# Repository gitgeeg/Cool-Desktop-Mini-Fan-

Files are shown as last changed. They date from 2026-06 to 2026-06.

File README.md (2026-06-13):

本作品旨在设计一款基于 ESP12F微控制器的智能桌面风扇控制器，具有PWM无级调速、自然风模式、VFD指示屏、ARGB灯光、联网时间显示以及检测环境光自动调整亮度的功能
-（是我的通用技术作业）
-This project aims to design an intelligent desktop fan controller based on the ESP12F microcontroller, featuring PWM continuous speed control, natural wind mode, VFD display screen, ARGB lighting, online time display, and the function of automatically adjusting brightness based on ambient light detection. 
-(This is my general technical assignment)
jpg

【通用技术作业实录】 https://www.bilibili.com/video/BV1krV56mEhq/?share_source=copy_web&vd_source=b246e824253217c284212f61fc7883cc
-此为该项目制作过程，该项目为搭棚焊接，暂无PCB图，原理图展示了硬件链接。附件有模型和源代码供各位参考
-推荐使用VS code + platformio插件 进行开发和固件下载
-加qq群546926675 一起讨论吧

[General Technology Project Record] https://www.bilibili.com/video/BV1krV56mEhq/?share_source=copy_web&vd_source=b246e824253217c284212f61fc7883cc
-This is the production process of this project. The project involves building a shed and welding. There is no PCB diagram yet. The schematic diagram shows the hardware connections. The attachment includes models and source codes for your reference.
-It is recommended to use VS code + platformio plugin for development and firmware download.
-Join the QQ group 546926675 to discuss together.

-Design process:
-Initially, it was envisioned to create a modular 12CM fan controller with a built-in 21700 battery and a long strip LCD screen. However, due to time and safety considerations, it was changed to using the existing and mature VFD display and an external power supply solution.
The VFD display module was a project designed by myself in March this year. At that time, I wrote mature and usable ESP12F driver code, and the open-source project link is: https://oshwhub.com/git-key/mi-ni-vfd-shi-zhong. It has the advantages of high brightness and contrast.
The fan uses Liming S12RW. To ensure an elegant appearance, an anti-rotating ARGB fan was needed. Only this one is available on the market at a reasonable price. The buzzer design was cancelled due to the insufficient pins of ESP12F.
-EC11, push buttons, etc. are all existing materials, suitable for completing this project within one week. The shell was initially made by sandblasted PLA 3D printing, and later, a more resilient and weather-resistant sandblasted PETG was chosen for printing. 
-Aesthetics principle: The color scheme and shape design of this work are elegant. The connection parts of the shell are rounded, the color is beautiful, and the overall design style is minimalist. 
-Innovative principle: The desktop fan is made intelligent and aesthetically pleasing, and a VFD screen design that is not available in the market has been incorporated. 
-Sustainable development principle: All the solder wires, fluxes, etc. in this product are lead-free. The modules comply with the RHOS standard and do not cause heavy metal pollution. The 3D printing materials selected are non-toxic to humans and recyclable and reusable. 
-Safety principle: External power supply, avoiding the risk of battery fire. All circuit soldering points are reinforced with electrical insulation UV glue to ensure safety. 
-Cost Estimation: 
-Limin S12RW fan x 1 24.6
-8-MD-06INKM VFD display 23.5 
-EC11 module 5.2
-ESP12F 5.74
-Resistors, capacitors, inductors 3.28
-Boost IC, LDO, diodes 2.7
-3D printing material cost 1.74
-Total: 24.6 + 23.5 + 5.2 + 5.74 + 3.28 + 2.7 + 1.74 = 66.76 RMB 
-The structure of the work conforms to mechanics: it is compatible with the shear force and the 3D printing layered structure, and the design is exquisite. 
-It offers diverse functions and rich ARGB lighting colors. It is highly extensible. The main control can be connected to WiFi and synchronize time via NTP. In the future, it can also remotely display various contents through ESP now communication, becoming a mobile terminal. 
-The human-computer interaction logic has been thoroughly verified and the design is extremely reasonable. With just the EC11 encoder, one can select fan mode, control ARGB lights, set automatic brightness, and so on.The operation is fast and convenient. 
-Innovation aspect: It is the only open-source project on the market that incorporates a VFD screen into a portable fan, setting a precedent for handheld fans to serve as both decorative items and handheld terminals. 
-Regarding the process of creating this work, it has enhanced my ability to withstand setbacks: I re-welded the main control and the fan twice and made dozens of changes to the model and code. It has also improved my -creativity: I independently completed the entire process of design, welding, 3D modeling, 3D printing adjustment, and embedded programming in less than a week, which has led to significant growth in all aspects of my abilities. 
-Material selection: 1. The VFD display module is an open-source project designed by myself in March this year. At that time, I wrote mature and usable ESP12F driver code, and it has the advantages of high brightness and contrast. 
-2. Materials such as EC11 and microswitches are all available and suitable for completing this project within one week. The outer shell was initially 3D-printed using matte PLA, and later was replaced with a more resilient and weather-resistant matte PETG for printing. 
-3. The photodiode was an element purchased for the previous film camera shutter speed measurement project. Its voltage range of 0 - 600mv is exactly within the sampling range of the microcontroller's ADC. 
-4. The esp12f microcontroller is inexpensive, has Wi-Fi functionality, has a sufficient number of pins and an ADC. It is an excellent choice for this project. 
-5. The 12cm fan uses Liming S12RW. To ensure an elegant appearance, an anti-rotation ARGB fan is required. Only this one is available on the market at a reasonable price. Structure: This controller and the fan body are designed with an upper and lower stacking structure. The center of gravity is at the bottom, which is placed on the desktop for stable and reliable operation, with an elegant appearance. It is connected by a PETG shell and 304 stainless steel m5 15mm screws, providing excellent weather resistance. Function: 
-6. Functions: PWM continuous speed control, natural wind mode, VFD display screen, ARGB lighting, network time display, and automatic brightness adjustment based on ambient light detection. All the functions are included, and the device has excellent maintainability and scalability: USB D+D- pins are linked to the TX/RX interface of the main controller, allowing for program flashing at any time. It can also be remotely controlled via ESP now communication, becoming a mobile terminal. 

-The initial design was for a modular 12CM fan controller that incorporated a built-in 21700 battery and featured a long strip LCD screen. However, due to time constraints and battery safety considerations, it was changed to use the existing and mature VFD display and an external power supply solution. 
-The buzzer design was cancelled because the ESP12F had insufficient pins.

-设计过程：
-最初设想为内置一节21700电池、使用长条形LCD屏幕的模块化12CM风扇控制器，但因时间、安全等因素改为使用现有且成熟的VFD显示屏以及外部供电方案。
-VFD显示模组为今年3月本人自己设计的项目，当时编写了成熟可用的ESP12F驱动代码，开源项目链接：https://oshwhub.com/git-key/mi-ni-vfd-shi-zhong 且具有高亮度与对比度的优点。
-风扇采用利民S12RW ，为了确保外观设计优雅故需要反叶ARGB风扇，市面上价格合适的仅此一款。蜂鸣器设计由于ESP12F引脚不足，故取消。
-EC11与 微动按钮 等材料都是现有的，适合一周内完成该项目。外壳最初采用磨砂PLA 3D打印，后选用更有韧性和耐候性的磨砂PETG打印。

-美观性原则：该作品配色与外形设计优雅，外壳链接部位做圆角处理，配色美观，整体为极简主义设计风格。

-创新性原则：将桌面风扇智能化、美观化并加入了市面上没用的VFD屏幕设计。

-可持续发展原则：该作品焊锡丝、助焊剂等全部无铅，模块符合RHOS标准，不造成重金属污染。3D打印材料选用无人体危害且可回收重复利用的PETG。

-安全性原则：外部供电、避免电池起火危险，全部电路焊接点都使用电气绝缘UV胶加固，保证安全。

-成本估算：

-利民S12RW风扇 x 1 24.6
-8-MD-06INKM VFD显示屏 23.5

-EC11模块 5.2
-ESP12F 5.74
-电阻、电容、电感元件 3.28
-升压IC 、LDO 、二极管 2.7
-3D打印材料费 1.74
-总计：24.6+23.5+5.2+5.74+3.28+2.7+1.74= 66.76人民币

-作品结构符合力学：抗剪切力和3D打印结构层叠结构相符，设计精巧

-实现功能多样，ARGB灯光色彩丰富。可扩展新极佳，主控可连接WiFi ntp同步时间，未来更可通过ESP now通讯远程显示各种内容，成为移动化终端。

-人机交互逻辑通过反复验证设计的十分合理，仅通过EC11编码器就可以选择风扇模式、控制ARGB灯光、设置自动亮度等等，操作快捷方便。

-创新方面：为市面上唯一将VFD屏幕加入到便携风扇的开源作品，开创了手持风扇作为摆件和手持终端双功能的先例。

-对于制作该作品的过程，锻炼了本人的抗挫能力：重新焊接主控和风扇各两次、数十次更改模型和代码。提升了本人的创造能力：仅仅用时一周不到独立完成了设计、焊接、3D建模、3D打印调参、嵌入式编程的全过程，使得自己各方面都得到了显著成长。

-选材： 
-1.VFD显示模组为今年3月本人自己设计的开源项目，当时编写了成熟可用的ESP12F驱动代码， 且具有高亮度与对比度的优点。

-2.EC11与 微动按钮 等材料都是现有的，适合一周内完成该项目。外壳最初采用磨砂PLA 3D打印，后选用更有韧性和耐候性的磨砂PETG打印。

-3.光电二极管为之前胶片相机快门测速器项目购买的元件，其电压范围0-600mv正好在微控制器adc的采样范围之内。

-4.esp12f微控制器价格低廉，有wifi功能，引脚数量够多且拥有一个adc。是本项目的极佳选择。

-5. 12cm风扇采用利民S12RW ，为了确保外观设计优雅故需要反叶ARGB风扇，市面上价格合适的仅此一款。 结构：本控制器与风扇主体采用上下堆叠设计，重心在下摆放在桌面稳定可靠，外形优雅。使用PETG外壳和304不锈钢m5 15mm螺丝连接件，耐候性极佳。 功

-6.功能：PWM无级调速、自然风模式、VFD指示屏、ARGB灯光、联网时间显示以及检测环境光自动调整亮度。功能应有尽有，且可维护性和扩展性极佳：usb d+d-引脚链接主控的TX/RX接口，可随时刷写程序。更可通过ESP now通讯远程控制，成为移动化终端。

-最初设想为内置一节21700电池、使用长条形LCD屏幕的模块化12CM风扇控制器，但因时间、电池安全等因素改为使用现有且成熟的VFD显示屏以及外部供电方案。

-蜂鸣器设计由于ESP12F引脚不足，故取消。

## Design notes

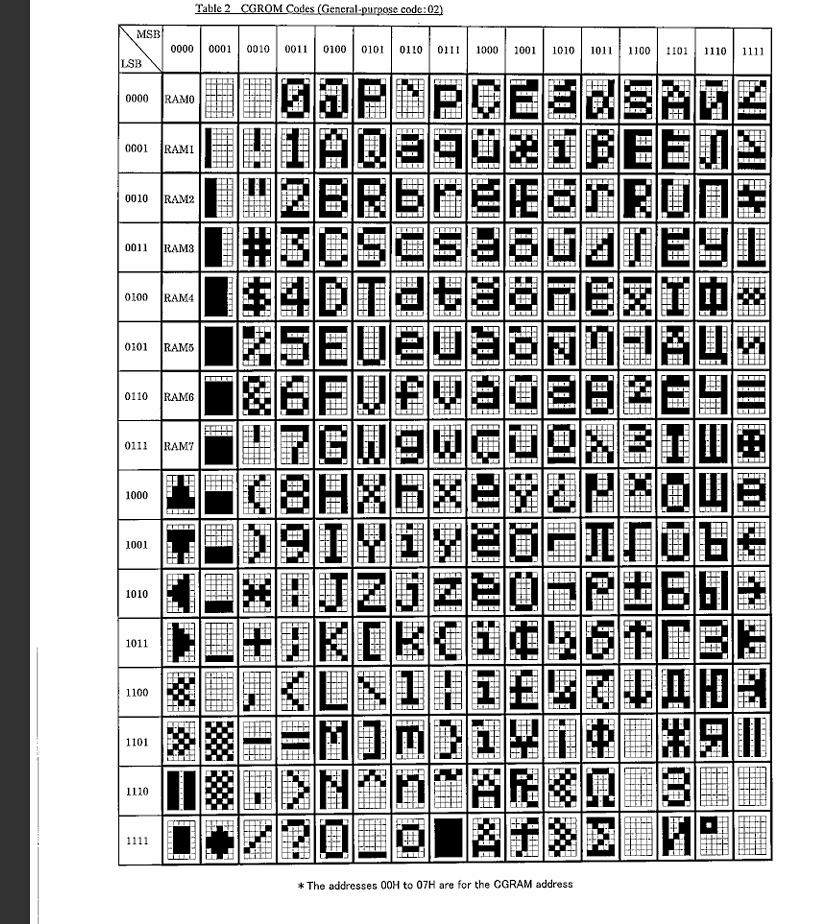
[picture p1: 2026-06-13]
Snipaste_2026-05-24_10-11-24.png

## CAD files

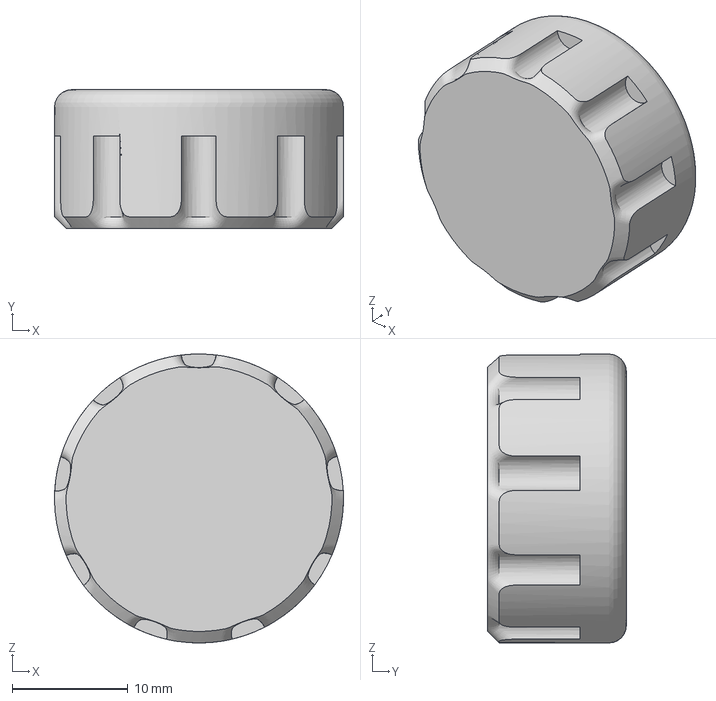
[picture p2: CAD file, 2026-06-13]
旋钮.3mf
25.0 x 12.0 x 25.0 mm

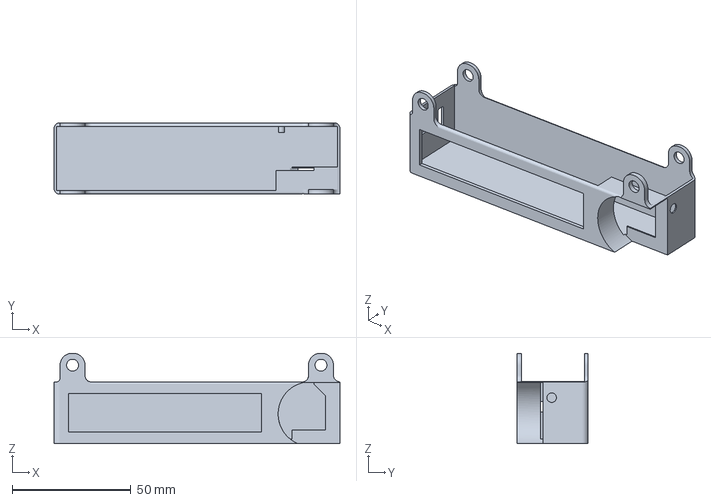
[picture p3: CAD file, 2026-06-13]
Fan.3mf
120.2 x 30.0 x 38.0 mm

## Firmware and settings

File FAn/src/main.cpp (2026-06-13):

/**
 * 智能风扇控制器 - ESP12F
 * ===========================
 * 功能:
 *   - PT6302 VFD 8位显示屏驱动
 *   - EC11 旋转编码器 (旋转+按压+长按+双击)
 *   - PWM 风扇速度控制
 *   - WS2812B ARGB 灯光控制
 *   - 光电二极管自动亮度调节
 *   - 自然风模式 (山谷回风)
 *   - 设置菜单 (省电模式 / 手动亮度)
 */

#include <Arduino.h>
#include <FastLED.h>
#include <ESP8266WiFi.h>
#include <time.h>

// ============================================================
// 1. 引脚定义
// ============================================================
// VFD 显示屏 (PT6302)
#define VFD_DIN   14   // DA 数据输入
#define VFD_CLK   16   // CK 时钟
#define VFD_CS    15   // CS 片选
#define VFD_RST   13   // RS 复位

// EC11 旋转编码器 (按键通过 A/B 序列超时检测, 无独立GPIO)
#define EC11_A    4    // GA  A相 (GPIO4)
#define EC11_B    12   // BB  B相 (GPIO12)

// 风扇
#define FAN_PWM   2    // PWM 风扇调速
#define FAN_ARGB  5    // ARGB 灯控 (WS2812B)

// 光电二极管 (ESP12F ADC / TOUT)
#define PHOTO_ADC A0   // 模拟输入 0-1V

// GPIO0 按键 (默认高电平, 低电平=按下, 用于开关风扇+RGB)
#define BTN_GPIO0 0

// ============================================================
// 2. 常量定义
// ============================================================

// --- VFD 显示位数 ---
#define VFD_DIGITS 8

// --- VFD 自定义字符 (PT6302 CGRAM / ROM) ---
// 风速档位条: 1竖 ~ 5竖
#define VFD_CHAR_BAR1   0x11
#define VFD_CHAR_BAR2   0x12
#define VFD_CHAR_BAR3   0x13
#define VFD_CHAR_BAR4   0x14
#define VFD_CHAR_BAR5   0x15
// 箭头
#define VFD_CHAR_LARROW 0x0A  // 左箭头
#define VFD_CHAR_RARROW 0x0B  // 右箭头
// 最小风速全亮
#define VFD_CHAR_ALLON  0x1D
// 风车动画帧
#define VFD_CHAR_PIPE   0x7C  // '|'
#define VFD_CHAR_SLASH  0x2F  // '/'
#define VFD_CHAR_DASH   0x2D  // '-'
#define VFD_CHAR_BSLASH 0x5C  // '\'
// 空格与空白
#define VFD_CHAR_SPACE  0x20
#define VFD_CHAR_BLANK  0x10

// --- 风速档位 (13档: 0关, 1=2格, 2~12每档+3格, 12级满35格) ---
#define FAN_LEVELS      13    // 0~12档
#define FAN_DISPLAY_POS 7     // 显示档位条的位置数 (1-7位)
#define FAN_BARS_PER_POS 5    // 每位置5段 (BAR1~BAR5)
// 13档位→格子数: level0=0, level1=2, level_n(2~12)=2+3*(n-1)
#define FAN_LEVEL1_BARS 2     // 第一档格子数
#define FAN_BARS_PER_STEP 3   // 之后每档+3格

// --- ARGB 灯光颜色模式 ---
enum ArgbMode : uint8_t {
    ARGB_SPEED_COLOR = 0,  // 随风扇档位变速 (蓝→黄→红)
    ARGB_BLUE,             // 浅蓝
    ARGB_WHITE,            // 白
    ARGB_ORANGE,           // 亮橙
    ARGB_RED,              // 红
    ARGB_RGB_CYCLE,        // 转圈RGB(逐灯珠)
    ARGB_RGB_ALL_CYCLE,    // 全体一起变RGB
    ARGB_OFF,              // 关闭
    ARGB_MODE_COUNT
};

// --- ARGB 灯光电源状态 ---
enum ArgbPower : uint8_t {
    ARGB_POWER_ON = 0,
    ARGB_POWER_OFF
};

// --- ARGB 亮度模式 ---
enum ArgbBrightMode : uint8_t {
    ARGB_BRIGHT_AUTO = 0,  // 跟随环境光
    ARGB_BRIGHT_MANUAL     // 手动
};

// --- 菜单/页面状态 ---
enum Page : uint8_t {
    PAGE_HOME = 0,          // 首页 - 风扇速度显示
    PAGE_ARGB_CONTROL,      // ARGB 灯光控制
    PAGE_SETTINGS,          // 设置菜单
    PAGE_POWER_SAVE,        // 省电模式设置
    PAGE_BRIGHTNESS_MANUAL, // 手动亮度调节
    PAGE_TIME               // 时间显示页面
};

// --- 设置项索引 ---
#define SETTING_POWER_SAVE      0
#define SETTING_BRIGHTNESS      1
#define SETTING_TIME            2
#define SETTING_COUNT           3

// --- 风扇模式 ---
enum FanMode : uint8_t {
    FAN_CONSTANT = 0,   // 定速模式
    FAN_NATURAL         // 自然风模式 (仅山谷回风)
};

// --- 亮度模式 ---
enum BrightnessMode : uint8_t {
    BRIGHT_AUTO = 0,    // 自动亮度
    BRIGHT_MANUAL       // 手动亮度
};

// --- 时间常量 (ms) ---
#define LONG_PRESS_MS       200   // ≥500ms=长按, <500ms=单点
#define DOUBLE_CLICK_MS     400
#define IDLE_TIMEOUT_MS     6000  // 6s无操作回首页
#define POWER_SAVE_IDLE_MS  5000
#define SPINNER_INTERVAL_MS 200
#define FAN_ADJ_TIMEOUT_MS  550   // 调速箭头快速恢复为风车动画

// --- 光电二极管 ADC 阈值 (ESP8266 10-bit ADC: 0-1023 对应 0-1V) ---
// 380mV→389 | 310mV→317 | 280mV→287 | 50mV→51
#define ADC_DARKEST    51
#define ADC_BRIGHTEST  389   // 380mV时屏幕亮度已达最大

// --- 亮度映射 ---
#define VFD_BRIGHT_MIN  40
#define VFD_BRIGHT_MAX  255

// --- ARGB LED 数量 (共15个灯珠) ---
#define ARGB_NUM_LEDS 15

// ============================================================
// 3. 全局变量
// ============================================================

// --- VFD 显示缓冲区 ---
uint8_t vfdPrevBuffer[VFD_DIGITS];

// --- EC11 编码器状态 (双下降沿 + 先后顺序) ---
volatile int32_t  encPosition = 0;        // 累计旋转位置
volatile int8_t   encSeqState = 0;        // 0=空闲 1=GA先低 2=BB先低
volatile unsigned long encGaFallMs = 0;   // GA下降时刻(ms)
volatile unsigned long encPressDuration = 0; // 按键持续时间ms (0=无)
int32_t  encLastRead = 0;

// 按键处理 (loop中消费 encPressDuration)
unsigned long encLastClickTime = 0;
uint8_t  encClickCount = 0;
bool     encClickPending = false;

// --- 编码器事件 ---
enum EncEvent : uint8_t {
    ENC_NONE = 0,
    ENC_ROTATE_CW,
    ENC_ROTATE_CCW,
    ENC_SINGLE_CLICK,
    ENC_DOUBLE_CLICK,
    ENC_LONG_PRESS
};

// --- 系统状态 ---
Page            currentPage = PAGE_HOME;
Page            prevPage = PAGE_HOME;
FanMode         fanMode = FAN_CONSTANT;
uint8_t         fanSpeed = 4;           // 当前档位 0~12 (默认中档)
uint8_t         fanDisplaySpeed = 6;    // 定速模式显示用档位
uint8_t         fanDisplaySmoothed = 0; // 自然风平滑显示用的竖格数 (0~35)
uint8_t         fanCurrentPWM = 0;      // 当前实际 PWM (平滑过渡)
uint8_t         fanTargetPWM = 0;       // 目标 PWM
bool            fanAdjusting = false;
bool            fanAdjustDir = true;

// --- ARGB 状态 ---
ArgbPower      argbPower = ARGB_POWER_ON;
ArgbMode       argbCurrentMode = ARGB_SPEED_COLOR;
ArgbMode       argbPreviewMode = ARGB_SPEED_COLOR;
ArgbBrightMode argbBrightMode = ARGB_BRIGHT_AUTO;
uint8_t        argbBrightness = 28;
uint8_t        argbManualBrightness = 128;
uint8_t        argbPreviewBrightness = 128;
uint16_t       argbCountIndex = 0;
unsigned long  argbCycleLastMs = 0;
bool           argbBrightnessMode = false;
uint8_t        argbRenderHue = 0;
uint8_t        argbSpeedHue = 160;        // SPEED_COLOR平滑目标色相
bool           argbInArgbPage = false;
CRGB           argbLeds[ARGB_NUM_LEDS];

// --- 亮度控制 ---
BrightnessMode  brightMode = BRIGHT_AUTO;
uint8_t         vfdBrightness = 200;
uint8_t         vfdManualBrightness = 200;
bool            powerSaveEnabled = true;

// --- GPIO0 按键状态 (开关风扇+RGB) ---
bool            gpio0PowerOn = true;       // 当前电源状态
bool            gpio0LastState = true;     // 上次GPIO0电平 (默认高)
unsigned long   gpio0DebounceMs = 0;       // 防抖计时
uint8_t         gpio0SavedFanSpeed = 6;    // 保存的风扇档位 0~12
FanMode         gpio0SavedFanMode = FAN_CONSTANT; // 保存的风扇模式
ArgbMode       gpio0SavedArgbMode = ARGB_SPEED_COLOR; // 保存的ARGB模式
uint8_t        gpio0SavedArgbBrightness = 128;      // 保存的ARGB亮度

// --- 自然风状态 (仅山谷回风) ---
unsigned long   naturalCycleStart = 0;
unsigned long   valleyGustNext = 0;
unsigned long   valleyCalmNext = 0;
bool            valleyInGust = false;
bool            valleyInCalm = false;

// --- 计时器 ---
unsigned long   lastUserAction = 0;
unsigned long   lastSpinnerUpdate = 0;
uint8_t         spinnerFrame = 0;

// --- 设置菜单 ---
bool            timeDisplayEnabled = true;  // 时间显示开关
uint8_t         settingIndex = 0;

// ============================================================
// 4. VFD 显示驱动
// ============================================================

void vfdWriteByte(uint8_t data) {
    for (uint8_t i = 0; i < 8; i++) {
        digitalWrite(VFD_CLK, LOW);
        digitalWrite(VFD_DIN, (data & 0x01) ? HIGH : LOW);
        data >>= 1;
        digitalWrite(VFD_CLK, HIGH);
    }
}

void vfdShow() {
    digitalWrite(VFD_CS, LOW);
    vfdWriteByte(0xE8);
    digitalWrite(VFD_CS, HIGH);
}

void vfdInit() {
    digitalWrite(VFD_CS, LOW);
    vfdWriteByte(0xE0);
    delayMicroseconds(5);
    vfdWriteByte(0x07);  // 8位
    digitalWrite(VFD_CS, HIGH);
    delayMicroseconds(5);

    digitalWrite(VFD_CS, LOW);
    vfdWriteByte(0xE4);
    delayMicroseconds(5);
    vfdWriteByte(200);
    digitalWrite(VFD_CS, HIGH);
    delayMicroseconds(5);
}

void vfdSetBrightness(uint8_t brightness) {
    digitalWrite(VFD_CS, LOW);
    vfdWriteByte(0xE4);
    delayMicroseconds(5);
    vfdWriteByte(brightness);
    digitalWrite(VFD_CS, HIGH);
    vfdBrightness = brightness;
}

void vfdWriteChar(uint8_t pos, uint8_t chr) {
    digitalWrite(VFD_CS, LOW);
    vfdWriteByte(0x20 + pos);
    vfdWriteByte(chr);
    digitalWrite(VFD_CS, HIGH);
}

void vfdClear() {
    for (uint8_t i = 0; i < VFD_DIGITS; i++) {
        vfdWriteChar(i, VFD_CHAR_BLANK);
        vfdPrevBuffer[i] = 0xFF;
    }
    vfdShow();
}

void vfdSetBuffer(const uint8_t* buf) {
    bool changed = false;
    for (uint8_t i = 0; i < VFD_DIGITS; i++) {
        if (buf[i] != vfdPrevBuffer[i]) {
            vfdWriteChar(i, buf[i]);
            vfdPrevBuffer[i] = buf[i];
            changed = true;
        }
    }
    if (changed) vfdShow();
}

// ============================================================
// 5. EC11 编码器中断处理
// ============================================================
// 同时检测 GA/BB 下降沿, 按先后顺序判定旋转
//   右旋 CW: BB↓先 → GA↓后 (BB先低)
//   左旋 CCW: GA↓先 → BB↓后 (GA先低)
// 按键: GA↓后 BB始终为HIGH, GA↑时记录持续时间
//        < 500ms → 单点 | ≥ 500ms → 长按
//
// 状态: 0=空闲 1=GA先低 2=BB先低
// 旋转: BB↓先→GA↓后=CW | GA↓先→BB↓后=CCW
// 按键: GA↓→GA↑且BB始终HIGH, 时长<100ms单点 ≥100ms长按

void IRAM_ATTR encISR() {
    uint8_t a = digitalRead(EC11_A);
    uint8_t b = digitalRead(EC11_B);

    if (a == LOW && b == LOW) {
        if (encSeqState == 1) encPosition--;
        if (encSeqState == 2) encPosition++;
        encSeqState = 0;
    }
    else if (a == LOW && b == HIGH) {
        if (encSeqState == 0) { encSeqState = 1; encGaFallMs = millis(); }
    }
    else if (a == HIGH && b == LOW) {
        if (encSeqState == 0) encSeqState = 2;
        if (encSeqState == 1) encSeqState = 0;
    }
    else {
        if (encSeqState == 1) {
            unsigned long dur = millis() - encGaFallMs;
            if (dur >= 80) encPressDuration = dur;
        }
        encSeqState = 0;
    }
}

void encInit() {
    pinMode(EC11_A, INPUT_PULLUP);
    pinMode(EC11_B, INPUT_PULLUP);
    attachInterrupt(digitalPinToInterrupt(EC11_A), encISR, CHANGE);
    attachInterrupt(digitalPinToInterrupt(EC11_B), encISR, CHANGE);
}

EncEvent encPoll() {
    unsigned long now = millis();
    static unsigned long lastEncEvent = 0;  // 统一防抖: 100ms内只记录首次操作

    // --- 1. 处理旋转 (位置变化) ---
    int32_t pos;
    noInterrupts();
    pos = encPosition;
    interrupts();

    if (pos != encLastRead) {
        int32_t old = encLastRead;
        encLastRead = pos; // 更新位置, 丢弃中间步数
        if (now - lastEncEvent >= 100) {
            EncEvent evt = (pos > old) ? ENC_ROTATE_CW : ENC_ROTATE_CCW;
            lastEncEvent = now;
            lastUserAction = now;
            return evt;
        }
    }

    // --- 2. 处理按键 (ISR记录的持续时间) ---
    unsigned long pressDur;
    noInterrupts();
    pressDur = encPressDuration;
    encPressDuration = 0;
    interrupts();

    if (pressDur > 0 && (now - lastEncEvent >= 100)) {
        lastEncEvent = now;
        lastUserAction = now;
        if (pressDur >= LONG_PRESS_MS) {
            encClickPending = false;
            encClickCount = 0;
            return ENC_LONG_PRESS;
        } else {
            encClickCount++;
            if (encClickCount == 1) {
                encLastClickTime = now;
                encClickPending = true;
            } else if (encClickCount >= 2) {
                encClickPending = false;
                encClickCount = 0;
                return ENC_DOUBLE_CLICK;
            }
        }
    }

    // --- 3. 单击超时判定 ---
    if (encClickPending && (now - encLastClickTime > DOUBLE_CLICK_MS)) {
        encClickPending = false;
        encClickCount = 0;
        lastEncEvent = now;
        lastUserAction = now;
        return ENC_SINGLE_CLICK;
    }

    return ENC_NONE;
}

// ============================================================
// 6. 风扇 PWM 控制 (35档 + 平滑变速)
// ============================================================

void fanInit() {
    pinMode(FAN_PWM, OUTPUT);
    analogWriteFreq(18000);  // 25kHz 静音 ******
    analogWrite(FAN_PWM, 0);
    fanCurrentPWM = 0;
    fanTargetPWM = 0;
}

/**
 * 设置风扇目标档位 (0-11), PWM 平滑过渡在 fanSmoothUpdate() 中完成
 */
void fanSetSpeed(uint8_t level) {
    if (level > 12) level = 12;
    fanTargetPWM = (level == 0) ? 0 : map(level, 1, 12, 20, 255);
    fanDisplaySpeed = level;
}

/**
 * 设置目标百分比 (0-100), 用于自然风模式
 * 显示档位由 fanCurrentPWM 实时反算, 确保平滑
 */
void fanSetTargetPercent(uint8_t percent) {
    if (percent > 100) percent = 100;
    fanTargetPWM = (percent == 0) ? 0 : map(percent, 1, 100, 20, 255);
}

/**
 * 将当前 PWM 反算为显示档位 (0-11)
 */
uint8_t pwmToDisplayLevel(uint8_t pwm) {
    if (pwm == 0) return 0;
    return constrain(map(pwm, 20, 255, 1, 12), 1, 12);
}

/**
 * 平滑过渡 PWM (每帧调用, 渐进式变速)
 */
void fanSmoothUpdate() {
    if (fanCurrentPWM == fanTargetPWM) return;

    int16_t diff = (int16_t)fanTargetPWM - (int16_t)fanCurrentPWM;
    int16_t step;

    // 步长: 加速快一些, 减速慢一些(更自然)
    if (abs(diff) > 50) {
        step = (diff > 0) ? 8 : -5;   // 大步快调
    } else if (abs(diff) > 10) {
        step = (diff > 0) ? 4 : -2;   // 中步
    } else {
        step = (diff > 0) ? 1 : -1;   // 微步精调
    }

    fanCurrentPWM = constrain(fanCurrentPWM + step, 0, 255);
    analogWrite(FAN_PWM, fanCurrentPWM);
}

/**
 * 立即设置 PWM (跳过平滑)
 */
void fanSetRawSpeed(uint8_t speed) {
    fanCurrentPWM = speed;
    fanTargetPWM = speed;
    analogWrite(FAN_PWM, speed);
}

/**
 * 设置目标百分比 (已废弃, 用 fanSetTargetPercent)
 */
void fanSetPercent(uint8_t percent) {
    fanSetTargetPercent(percent);
}

// ============================================================
// 7. ARGB 灯光控制 (WS2812B)
// ============================================================
// 前向声明 (第8节定义)
uint16_t photoRead();
uint8_t photoToBrightness(uint16_t adc);

void argbInit() {
    FastLED.addLeds<WS2812B, FAN_ARGB, GRB>(argbLeds, ARGB_NUM_LEDS);
    FastLED.setBrightness(128);
    FastLED.clear();
    ets_intr_lock();
    FastLED.show();
    delayMicroseconds(100);
    FastLED.show();
    ets_intr_unlock();
}

/** 全部熄灭 (硬件级中断锁+双重发送) */
void argbAllOff() {
    FastLED.clear();
    uint8_t pwmVal = fanCurrentPWM;
    digitalWrite(FAN_PWM, LOW);
    ets_intr_lock();
    FastLED.show();
    delayMicroseconds(100);
    FastLED.show();
    ets_intr_unlock();
    analogWrite(FAN_PWM, pwmVal);
}

/** 根据模式刷新所有灯珠 */
void argbRender(ArgbMode mode, uint8_t brightness) {
    FastLED.setBrightness(brightness);
    FastLED.clear();

    switch (mode) {
        case ARGB_SPEED_COLOR:
            // 风扇档位→颜色: 低=蓝(160°) 中=黄(64°) 高=红(0°), 3s完成全程平滑
            {
                uint8_t target = map(fanCurrentPWM, 0, 255, 160, 0);
                // 每200ms步进10, 全程160/10=16步=3.2s≈3s
                int16_t diff = (int16_t)target - (int16_t)argbSpeedHue;
                if (diff > 0) { argbSpeedHue += (diff > 10) ? 10 : diff; }
                else if (diff < 0) { argbSpeedHue -= ((-diff) > 10) ? 10 : (-diff); }
                fill_solid(argbLeds, ARGB_NUM_LEDS, CHSV(argbSpeedHue, 255, 255));
            }
            break;
        case ARGB_BLUE:
            fill_solid(argbLeds, ARGB_NUM_LEDS, CRGB(0, 255, 200)); 
            break;
        case ARGB_ORANGE:
            fill_solid(argbLeds, ARGB_NUM_LEDS, CRGB(255, 60, 0)); 
            break;
        case ARGB_WHITE:
            fill_solid(argbLeds, ARGB_NUM_LEDS, CRGB::White);
            break;
        case ARGB_RED:
            fill_solid(argbLeds, ARGB_NUM_LEDS, CRGB::Red);
            break;
        case ARGB_RGB_CYCLE:
            for (uint16_t i = 0; i < ARGB_NUM_LEDS; i++) {
                argbLeds[i] = CHSV((uint8_t)(argbRenderHue + i * (255 / ARGB_NUM_LEDS)), 255, 255);
            }
            break;
        case ARGB_RGB_ALL_CYCLE:
            fill_solid(argbLeds, ARGB_NUM_LEDS, CHSV(argbRenderHue, 255, 255));
            break;
        case ARGB_OFF:
            break;
        default: break;
    }
    // 硬件级中断锁 + 临时静默PWM引脚 + 双重发送抗噪声
    uint8_t pwmVal = fanCurrentPWM;            // 保存当前PWM
    digitalWrite(FAN_PWM, LOW);                // PWM引脚拉低, 减少噪声
    ets_intr_lock();                           // 硬件级关全部中断
    FastLED.show();                            // 第一次发送
    delayMicroseconds(100);                    // 等待噪声消退
    FastLED.show();                            // 第二次发送 (覆盖残留错误)
    ets_intr_unlock();                         // 恢复中断
    analogWrite(FAN_PWM, pwmVal);              // 恢复PWM
}

static unsigned long argbLastRender = 0;  // 统一渲染计时

/** 切换模式/页面时重置渲染定时器, 确保立即响应 */
void argbResetRenderTimer() { argbLastRender = 0; }

/** RGB色相 + SPEED_COLOR定时刷新 (统一计时器, 无延迟) */
void argbCycleUpdate() {
    unsigned long now = millis();
    if (currentPage == PAGE_ARGB_CONTROL || argbPower != ARGB_POWER_ON) return;

    // 统一计时: RGB 50ms, SPEED_COLOR 200ms, 其余不刷
    uint16_t interval = 200;
    if (argbCurrentMode == ARGB_RGB_CYCLE || argbCurrentMode == ARGB_RGB_ALL_CYCLE) interval = 50;
    else if (argbCurrentMode != ARGB_SPEED_COLOR) return;

    if (now - argbLastRender < interval) return;
    argbLastRender = now;

    if (argbCurrentMode == ARGB_RGB_CYCLE || argbCurrentMode == ARGB_RGB_ALL_CYCLE) {
        argbRenderHue++;
    }
    argbRender(argbCurrentMode, argbBrightness);
}

/** ARGB 亮度自动更新 (跟随环境光, 关中断刷新) */
void argbBrightnessUpdate() {
    if (argbBrightMode != ARGB_BRIGHT_AUTO) return;
    static unsigned long lastUpdate = 0;
    unsigned long now = millis();
    if (now - lastUpdate < 300) return;  // 加快到300ms
    lastUpdate = now;

    uint8_t target = photoToBrightness(photoRead());
    // 步进3, 加速响应
    if (argbBrightness < target) argbBrightness += min(3, target - argbBrightness);
    else if (argbBrightness > target) argbBrightness -= min(3, argbBrightness - target);

    FastLED.setBrightness(argbBrightness);
    if (currentPage == PAGE_ARGB_CONTROL) {
        if (argbBrightnessMode) argbPreviewBrightness = argbBrightness;
    } else {
        uint8_t pwmVal = fanCurrentPWM;
        digitalWrite(FAN_PWM, LOW);
        ets_intr_lock();
        FastLED.show();
        delayMicroseconds(100);
        FastLED.show();
        ets_intr_unlock();
        analogWrite(FAN_PWM, pwmVal);
    }
}

// ============================================================
// 8. 光电二极管 & 自动亮度 (3秒滑动平均)
// ============================================================

#define ADC_SAMPLE_MS   1000  // 每1s采样一次
#define ADC_WINDOW      3     // 3s / 1s = 3个样本

static uint16_t adcBuffer[ADC_WINDOW] = {0};
static uint8_t  adcIndex = 0;
static uint16_t adcSum = 0;
static uint8_t  adcCount = 0;

/**
 * 读取光电二极管 ADC (3秒滑动平均)
 */
uint16_t photoRead() {
    static unsigned long lastSample = 0;
    unsigned long now = millis();
    if (now - lastSample >= ADC_SAMPLE_MS) {
        lastSample = now;
        uint16_t raw = analogRead(PHOTO_ADC);
        if (adcCount < ADC_WINDOW) {
            adcSum += raw;
            adcCount++;
        } else {
            adcSum = adcSum - adcBuffer[adcIndex] + raw;
        }
        adcBuffer[adcIndex] = raw;
        adcIndex = (adcIndex + 1) % ADC_WINDOW;
    }
    if (adcCount == 0) return analogRead(PHOTO_ADC);
    return adcSum / adcCount;
}
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
void loop() {
    unsigned long now = millis();

    // 1. 编码器事件
    EncEvent event = encPoll();
    if (event != ENC_NONE) {
        handleEncEvent(event);
        lastUserAction = now;
    }

    // 1b. GPIO0 按键检测 (低电平=按下, 防抖50ms)
    bool gpio0Curr = digitalRead(BTN_GPIO0);
    if (gpio0Curr == LOW && gpio0LastState == HIGH) {
        gpio0DebounceMs = now;
    }
    if (gpio0Curr == HIGH && gpio0LastState == LOW && (now - gpio0DebounceMs >= 50)) {
        if (gpio0PowerOn) {
            // 关闭: 仅停风扇, ARGB保持开启, 保存模式状态
            gpio0SavedFanSpeed = fanSpeed;
            gpio0SavedFanMode = fanMode;
            gpio0SavedArgbMode = argbCurrentMode;
            gpio0SavedArgbBrightness = argbBrightness;
            fanSetRawSpeed(0);
            fanMode = FAN_CONSTANT;
            gpio0PowerOn = false;
            // 切换到首页显示 0x1D
            if (currentPage != PAGE_HOME) switchPage(PAGE_HOME);
            Serial.println("[GPIO0] 关闭风扇");
        } else {
            // 开启: 恢复风扇和模式
            fanSpeed = gpio0SavedFanSpeed;
            fanMode = gpio0SavedFanMode;
            if (fanMode == FAN_CONSTANT) {
                fanSetSpeed(fanSpeed);
            } else {
                naturalCycleStart = millis();
                valleyGustNext = valleyCalmNext = 0;
                valleyInGust = valleyInCalm = false;
                fanSetSpeed(fanSpeed);
            }
            gpio0PowerOn = true;
            if (currentPage != PAGE_HOME) switchPage(PAGE_HOME);
            Serial.println("[GPIO0] 开启风扇");
        }
    }
    gpio0LastState = gpio0Curr;

    // 2. 风扇 PWM 平滑变速 (每帧都执行)
    fanSmoothUpdate();

    // 3. 自然风更新 (通电时始终运行, 不限页面)
    if (gpio0PowerOn && fanMode == FAN_NATURAL) {
        naturalWindUpdate();
    }

    // 4. ARGB RGB循环更新 + 亮度自动
    argbCycleUpdate();
    argbBrightnessUpdate();

    // 5. 亮度控制
    if (brightMode == BRIGHT_AUTO) {
        brightnessUpdate();
    } else if (brightMode == BRIGHT_MANUAL && powerSaveEnabled) {
        // 手动亮度+省电模式: 5s无操作降为40%
        static unsigned long lastBrightUpdate = 0;
        if (now - lastBrightUpdate >= 500) {
            lastBrightUpdate = now;
            if (now - lastUserAction > POWER_SAVE_IDLE_MS) {
                uint8_t target = (uint16_t)vfdManualBrightness * 40 / 100;
                if (target < 5) target = 5;
                if (vfdBrightness != target) vfdSetBrightness(target);
            } else {
                if (vfdBrightness != vfdManualBrightness) vfdSetBrightness(vfdManualBrightness);
            }
        }
    }

    // 6. 调试串口输出
    debugPrint();

    // 7. 显示更新
    displayUpdate();

    // 8. 空闲超时 & 时间页面切换
    checkIdleTimeout();
    checkTimeSwitch();

    // 9. 调速箭头快速恢复为风车动画 (250ms)
    static unsigned long fanAdjTimeout = 0;
    if (fanAdjusting && currentPage == PAGE_HOME) {
        if (fanAdjTimeout == 0) fanAdjTimeout = now;
        if (now - fanAdjTimeout > FAN_ADJ_TIMEOUT_MS) { fanAdjusting = false; fanAdjTimeout = 0; }
    } else {
        fanAdjTimeout = 0;
    }
}
